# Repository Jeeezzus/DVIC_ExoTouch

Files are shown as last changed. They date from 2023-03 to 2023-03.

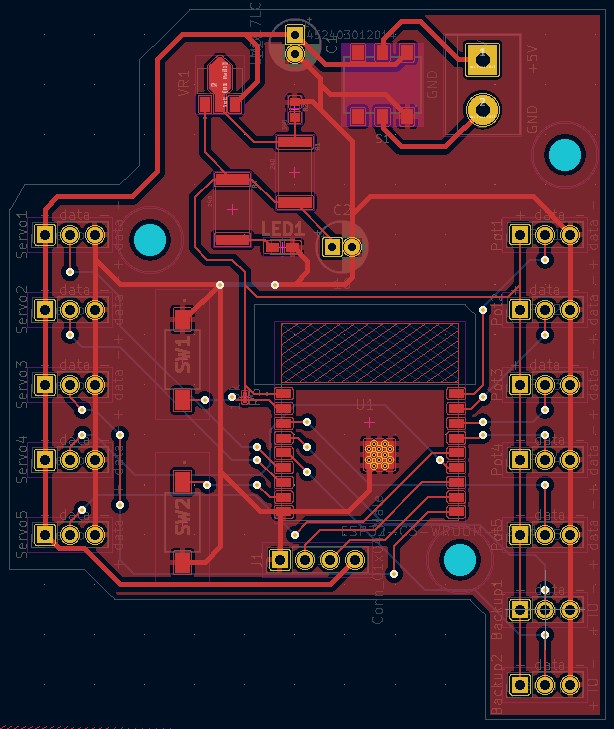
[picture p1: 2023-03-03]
HARDWARE/PCB/ScreenPCB.jpg

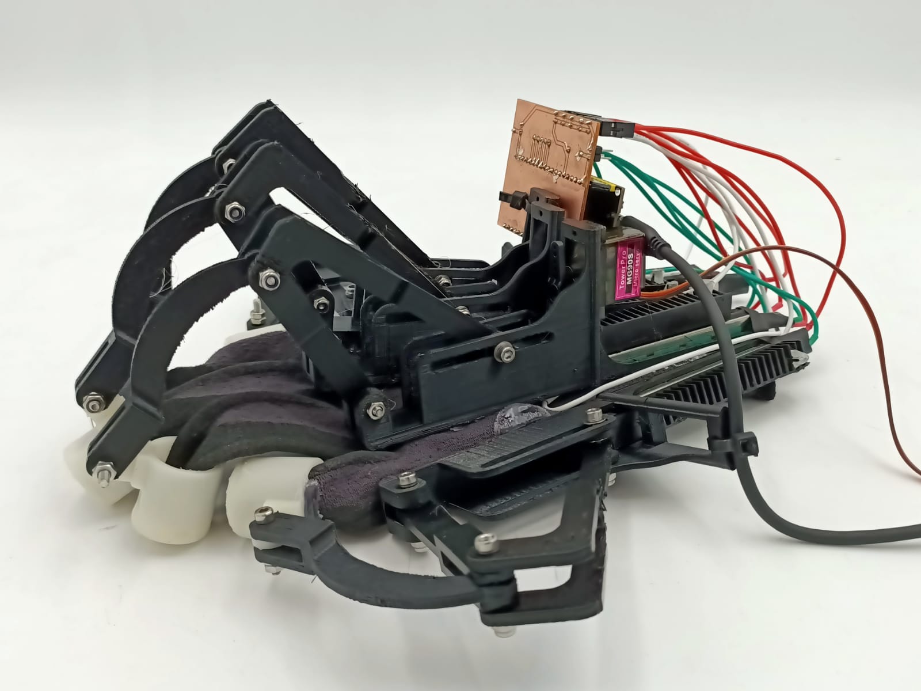
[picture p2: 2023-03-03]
Pictures/ExoTouchV2Packshot.jpeg

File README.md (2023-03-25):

# ExoTouch - DIY VR Haptic Glove

ExoTouch is an open-source project aimed at developing a DIY VR haptic glove that provides a realistic sense of touch for virtual reality experiences. This repository contains the hardware and software designs for several prototypes of the ExoTouch glove.

## Overview

We have produced several versions of the ExoTouch glove, each with different architectures and features, based on the  Lucid Glove: a cheap VR haptic glove that only requires potentiometers, servo motors, strings, and an ESP. It was designed By Lucas VRTech (all credits to https://github.com/LucidVR/lucidgloves)

The ExoTouch V1 is based on a three-piece exoskeleton that pulls a toothed bar that a servo-motor can lock to provide haptic feedback. The system was enhanced with a rudimentary PCB to control the servo motors and send the potentiometer information to the computer.

ExoTouch V2 was a prototype using a semi-rigid tube to connect the front of the finger to the potentiometer. However, this design was not promising and was quickly abandoned.

Finally, ExoTouch V3 is the latest version of the glove, based on the work of Nick Iacobbo. This exoskeleton follows each phalange of the hand, allowing much more efficient tracking of the position of the fingers. The potentiometers have been mounted on the back of the hand, offering better wrist flexibility. A rudimentary PCB has been added to send the potentiometer values to the computer, using an ESP32-based MCU board. This board includes a charge controller, allowing a battery to be directly connected to the ESP, making the glove wireless.

## Force Feedback System

The ExoTouch V3 introduced a new force feedback system, similar to bike brakes. Two brake plates are pressed against the potentiometer's moving part, introducing a friction force that blocks the fingers. Although the force feedback system is not as powerful as some commercial haptic gloves, it provides a realistic sense of touch for VR experiences.

## Limitations and Future Work

The ExoTouch gloves still have some limitations, including the force feedback system not being as strong as commercial gloves, the need to place the controller at the back of the hand, and the volume of the glove being a bit too large. However, we believe that this project can be improved by developing more powerful force feedback systems, improving the glove design, exploring alternative control mechanisms, and conducting further user studies to better understand the needs of different user groups.

## Conclusion

ExoTouch is a DIY VR haptic glove project that aims to provide a more immersive virtual reality experience. By sharing our designs and code, we hope to encourage others to experiment and improve upon our work. We welcome feedback, contributions, and collaborations from the community.

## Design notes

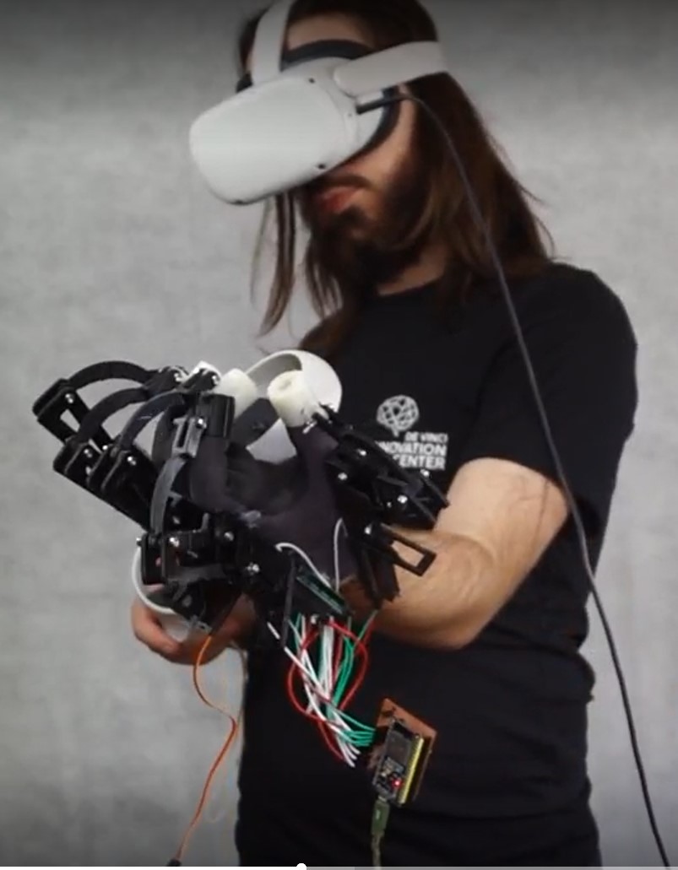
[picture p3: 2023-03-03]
Pictures/Using2.jpg

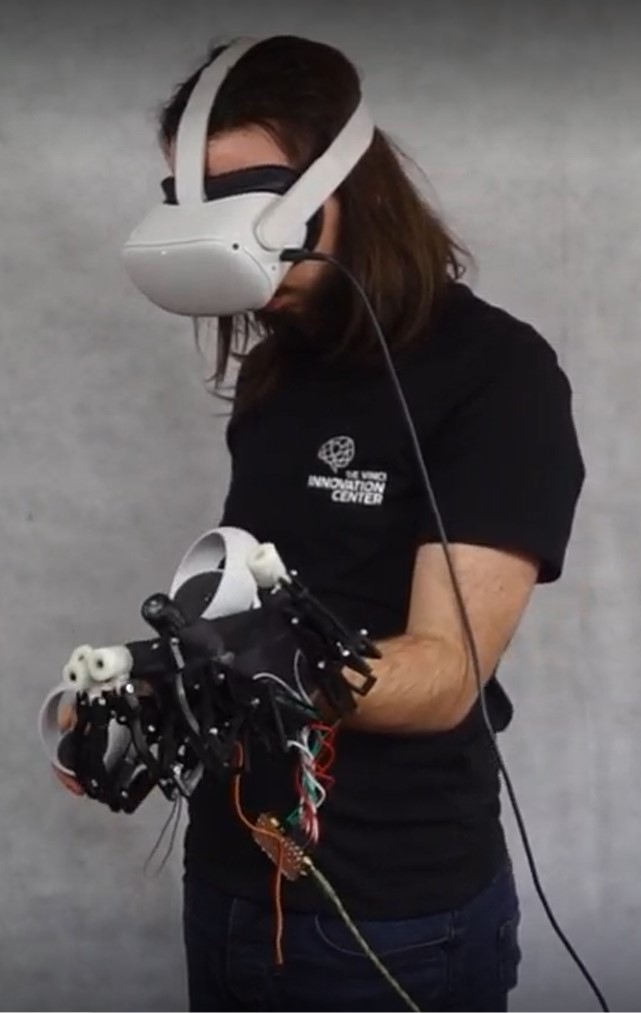
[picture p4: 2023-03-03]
Pictures/Using.jpg

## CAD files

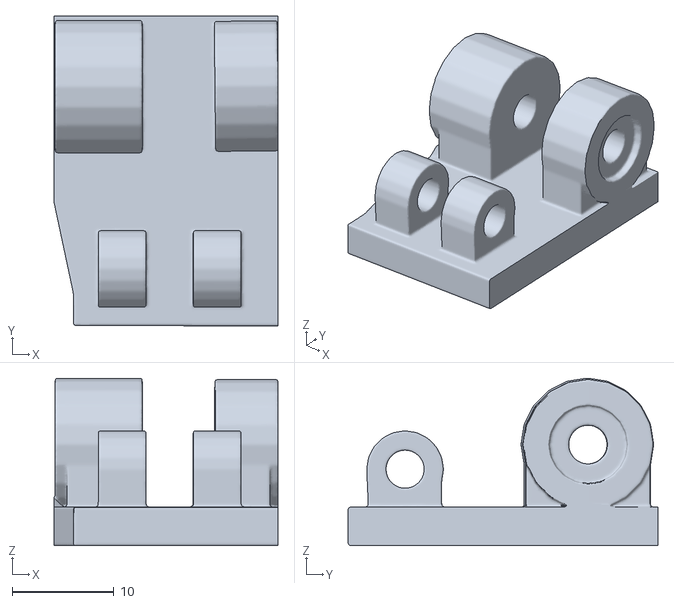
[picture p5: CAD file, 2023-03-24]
HARDWARE/V3/STL Files/GloveHolder.stl
22.0 x 30.5 x 16.5

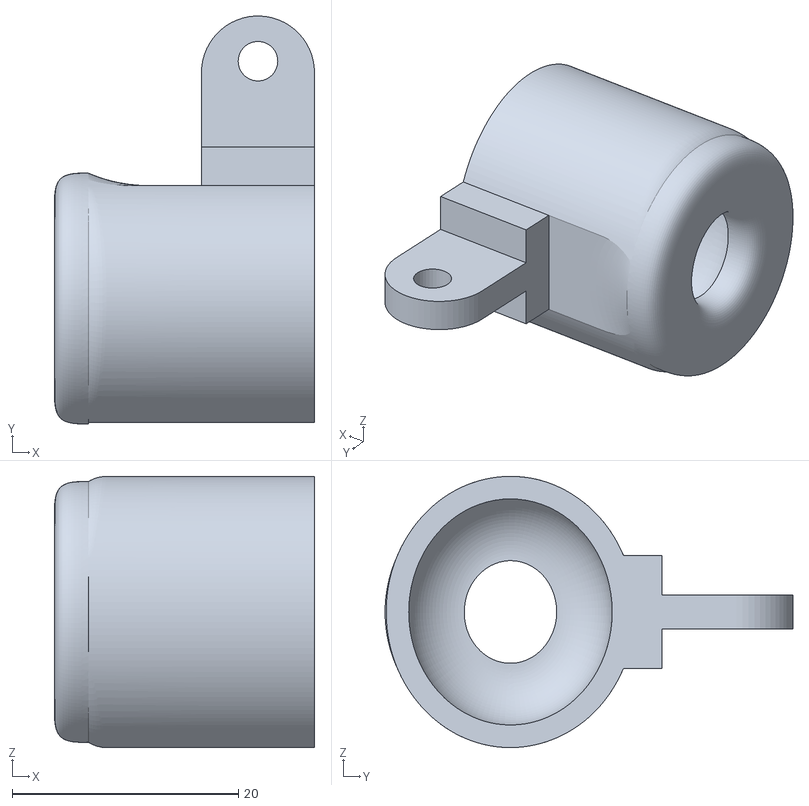
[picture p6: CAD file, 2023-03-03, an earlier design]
HARDWARE/V1/Cover doigt.stl
23.0 x 36.1 x 24.0

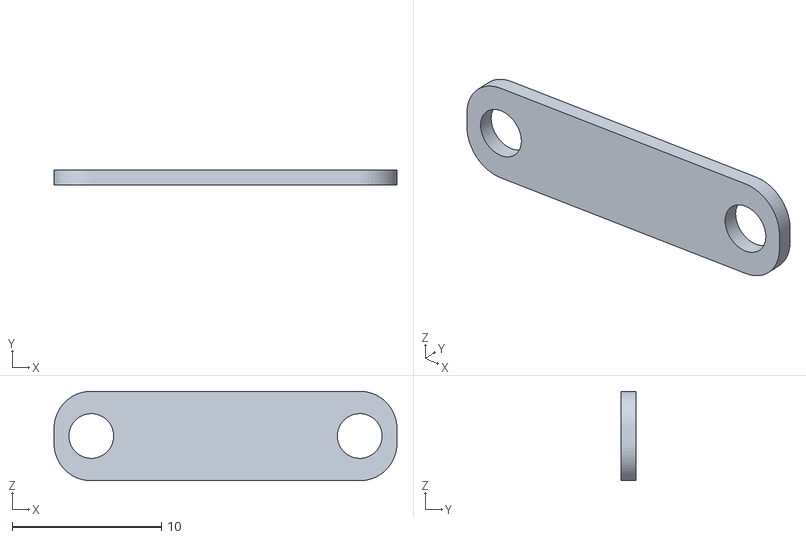
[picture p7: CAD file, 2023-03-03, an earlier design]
HARDWARE/V2/A23.stl
23.0 x 1.00 x 6.00

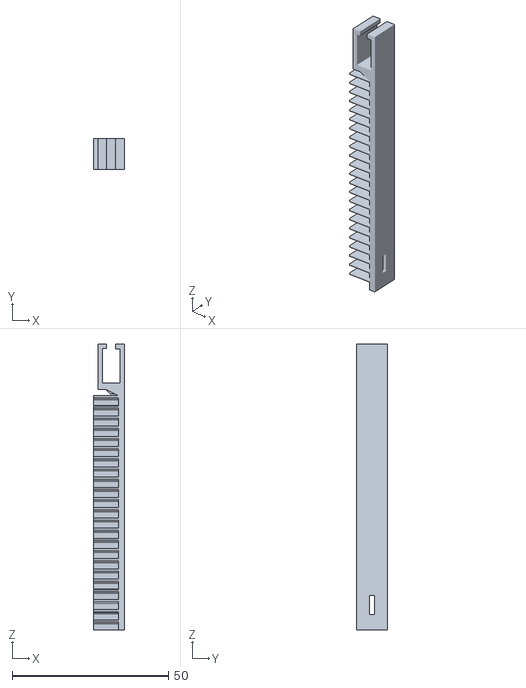
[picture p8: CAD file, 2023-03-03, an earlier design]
HARDWARE/V1/CoverPotard.stl
10.0 x 10.0 x 91.5

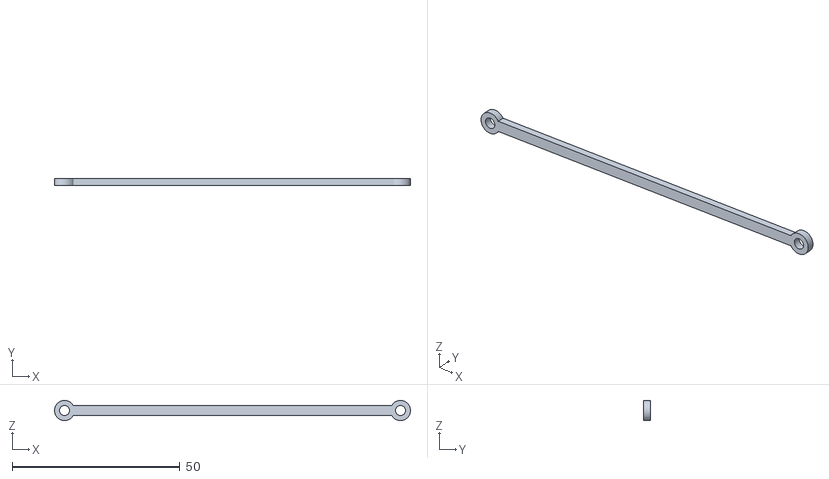
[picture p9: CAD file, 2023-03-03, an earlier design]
HARDWARE/V2/PSlider v2.stl
106.0 x 2.00 x 6.00

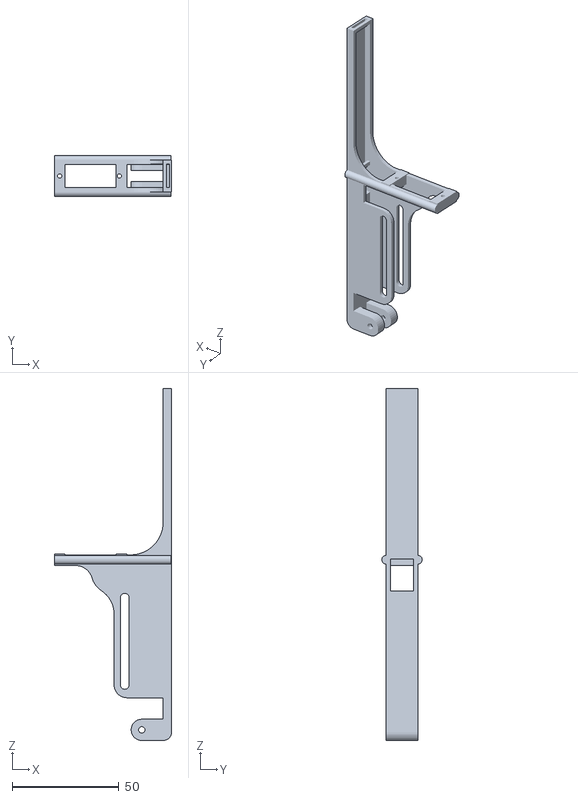
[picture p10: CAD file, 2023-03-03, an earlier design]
HARDWARE/V1/SupportPotard.stl
55.0 x 19.0 x 165.0

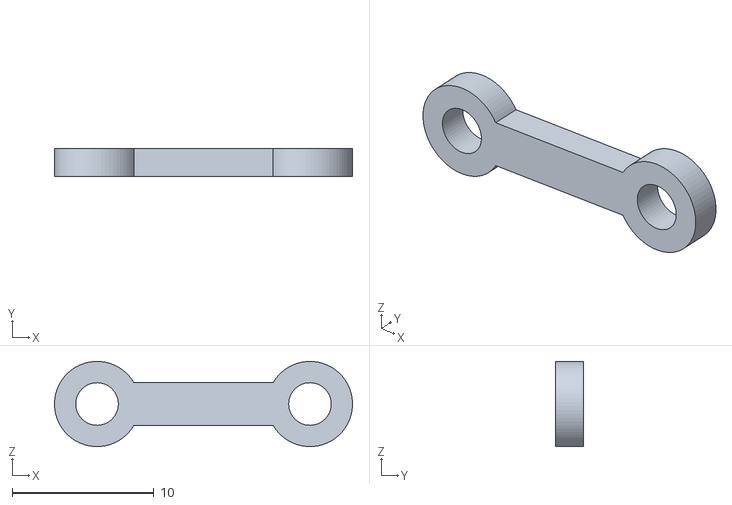
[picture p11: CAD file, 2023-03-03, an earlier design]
HARDWARE/V2/PUP.stl
21.0 x 2.00 x 6.00

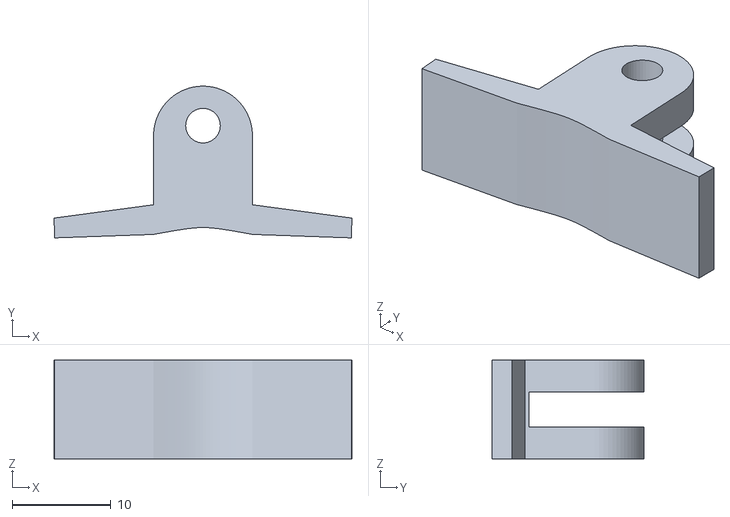
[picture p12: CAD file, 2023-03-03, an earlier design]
HARDWARE/V1/acrocheP1.stl
30.1 x 15.3 x 10.0

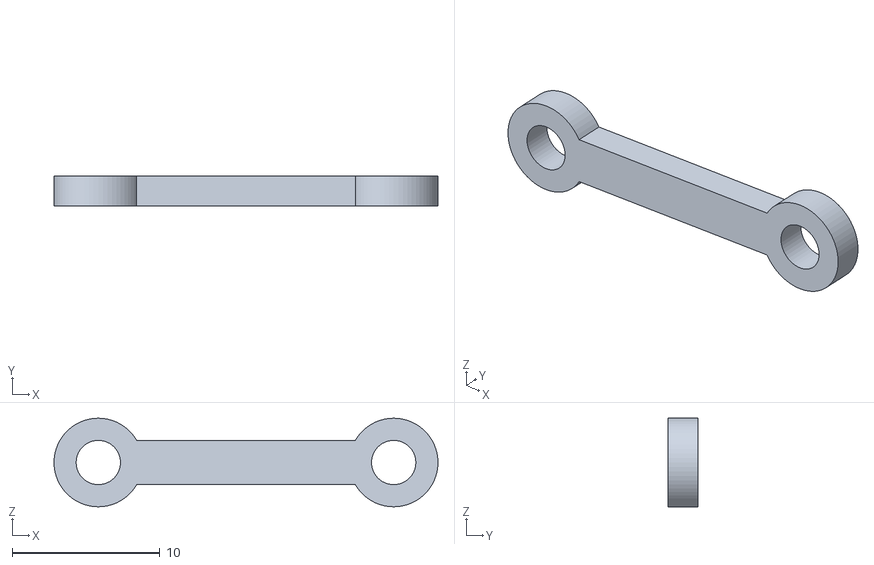
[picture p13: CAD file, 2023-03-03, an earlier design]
HARDWARE/V2/PUPBACK.stl
26.0 x 2.00 x 6.00

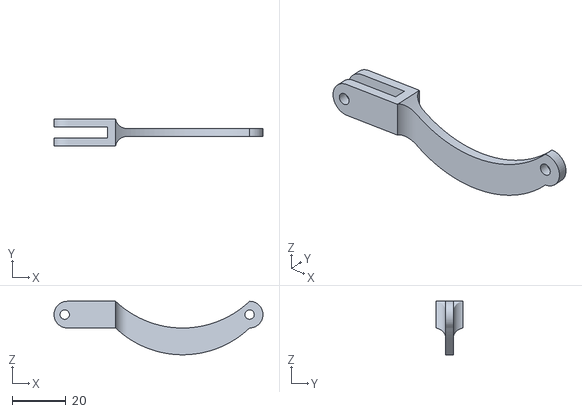
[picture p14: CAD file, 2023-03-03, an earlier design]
HARDWARE/V1/Courbe.stl
78.0 x 10.0 x 20.0

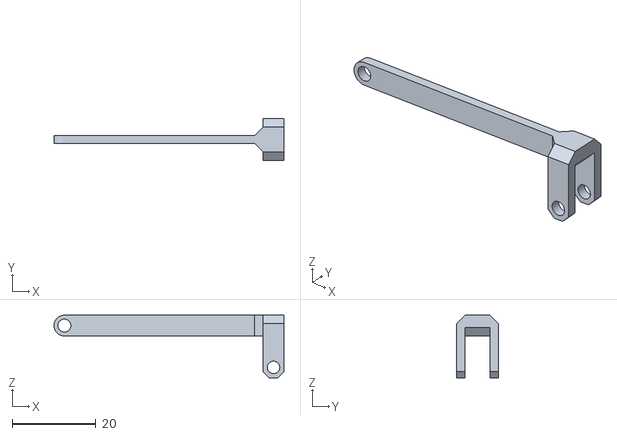
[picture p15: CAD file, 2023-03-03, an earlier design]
HARDWARE/V2/BarreP1.stl
55.0 x 10.0 x 15.0

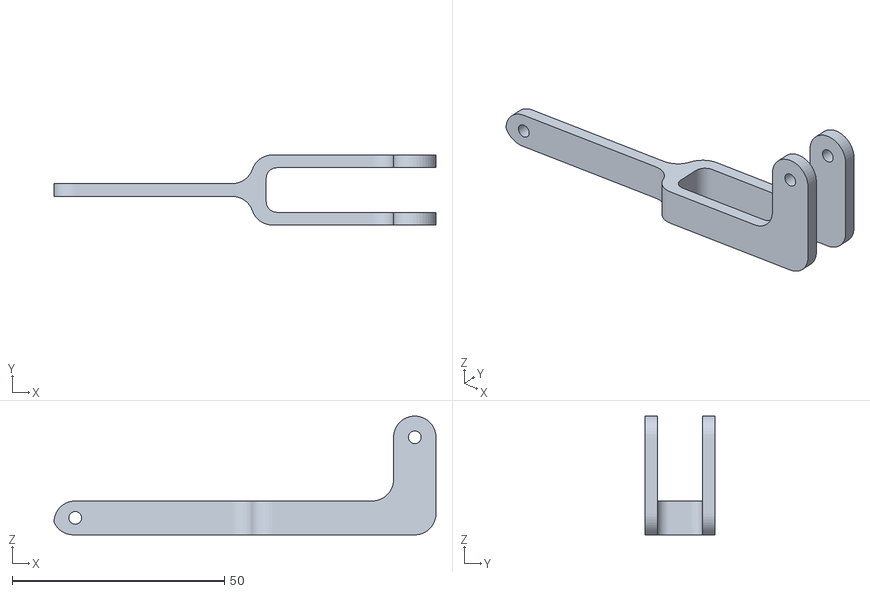
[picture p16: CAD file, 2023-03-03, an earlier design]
HARDWARE/V1/Barre 3.stl
90.0 x 16.5 x 28.0

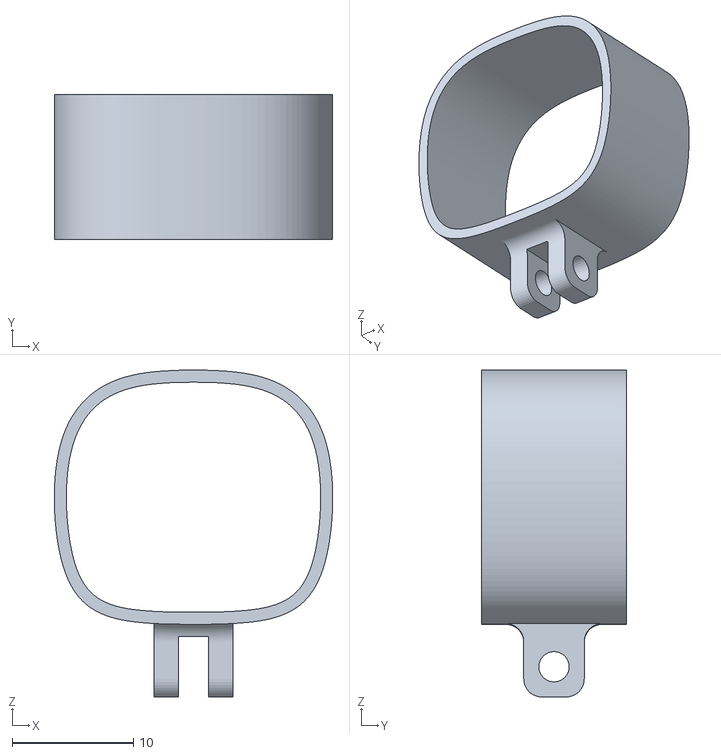
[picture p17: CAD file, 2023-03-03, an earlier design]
HARDWARE/V2/P2.stl
23.0 x 12.0 x 27.0

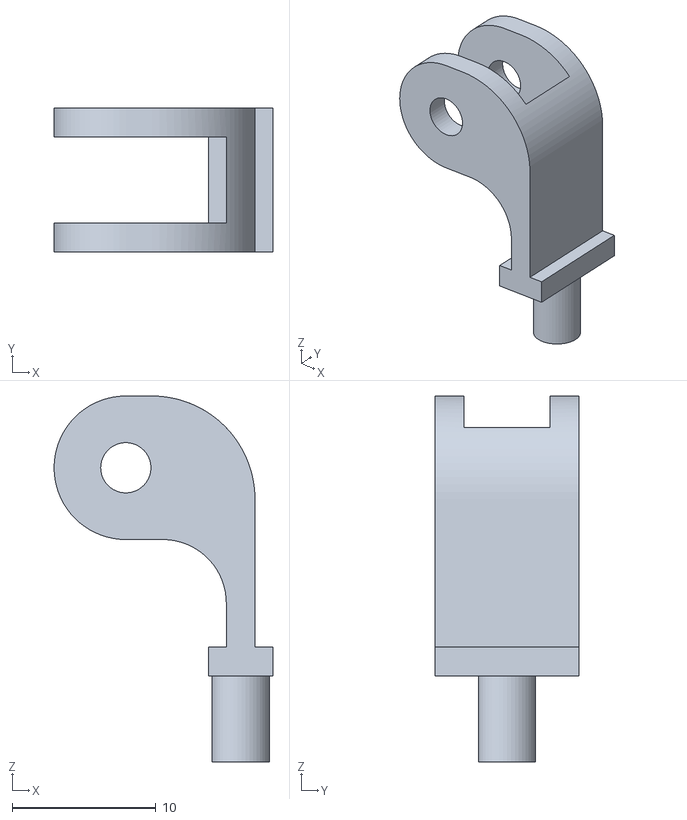
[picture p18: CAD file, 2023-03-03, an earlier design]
HARDWARE/V1/Pusher.stl
15.2 x 10.0 x 25.5

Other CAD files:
HARDWARE/V2/PBack.stl
HARDWARE/V1/B2.stl
HARDWARE/V2/A12.stl
HARDWARE/V2/P3.stl

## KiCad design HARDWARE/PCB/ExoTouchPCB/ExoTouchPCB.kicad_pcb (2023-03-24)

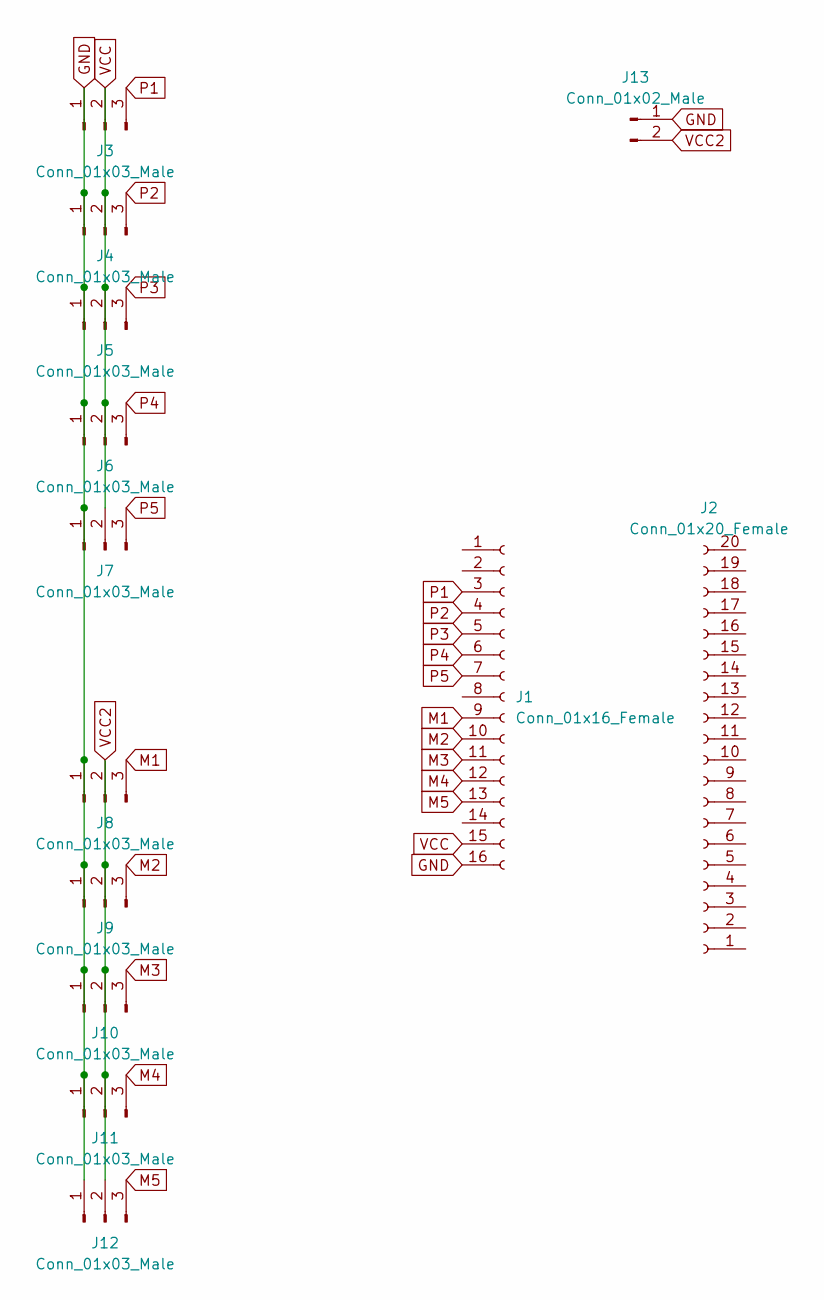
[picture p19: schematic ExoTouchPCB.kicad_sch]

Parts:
J1: Conn_01x16_Female; PinHeader_1x16_P2.54mm_Vertical
J2: Conn_01x20_Female; PinHeader_1x20_P2.54mm_Vertical
J3, J4, J5, J6, J7, J8, J9, J10, J11, J12: Conn_01x03_Male; PinHeader_1x03_P2.54mm_Vertical
J13: Conn_01x02_Male; PinHeader_1x02_P2.54mm_Vertical

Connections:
GND: J1.16, J3.1, J4.1, J5.1, J6.1, J7.1, J8.1, J9.1, J10.1, J11.1, J12.1, J13.1
M1: J1.9, J8.3
M2: J1.10, J9.3
M3: J1.11, J10.3
M4: J1.12, J11.3
M5: J1.13, J12.3
P1: J1.3, J3.3
P2: J1.4, J4.3
P3: J1.5, J5.3
P4: J1.6, J6.3
P5: J1.7, J7.3
VCC: J1.15, J3.2, J4.2, J5.2, J6.2, J7.2
VCC2: J8.2, J9.2, J10.2, J11.2, J12.2, J13.2

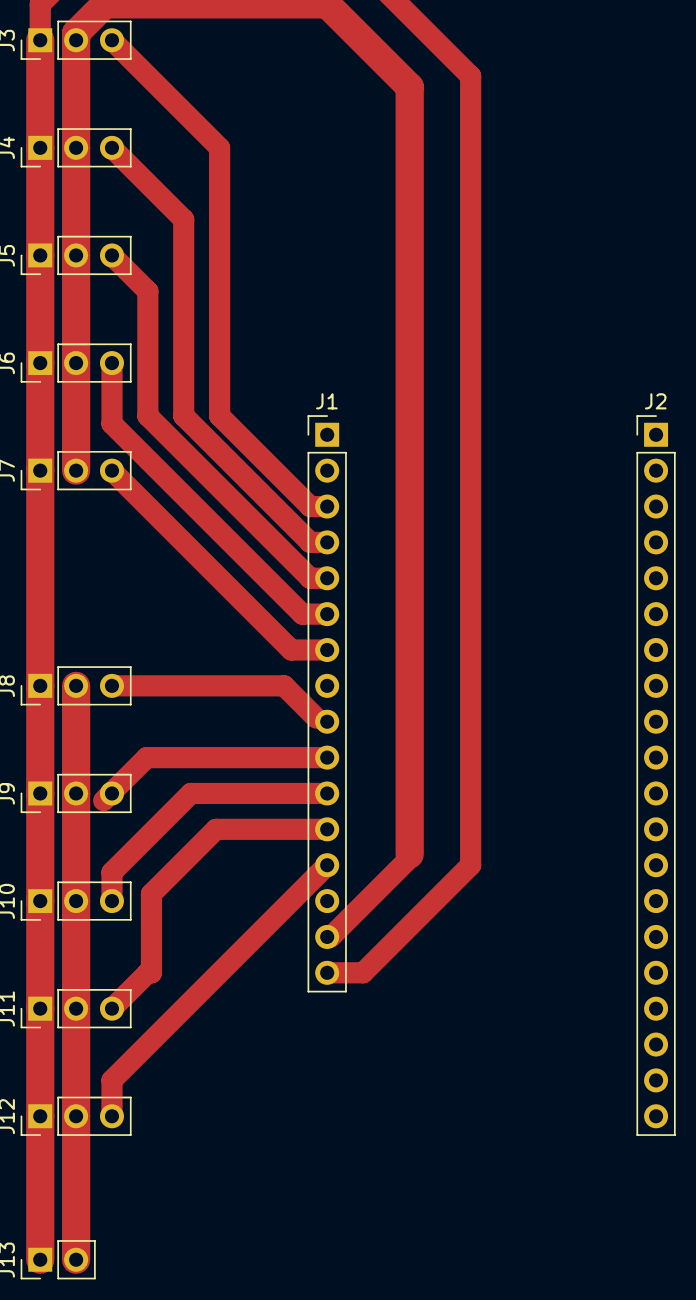
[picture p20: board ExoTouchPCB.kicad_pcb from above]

Board: 2 copper layers, 13 parts (0 on the bottom side), 13 nets.

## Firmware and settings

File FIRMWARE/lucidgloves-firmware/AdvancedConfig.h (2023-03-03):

//Advanced settings, only for the pros XD

#define LOOP_TIME 1 //How much time between data sends (ms), set to 0 for a good time :)
#define CALIBRATION_LOOPS -1//How many loops should be calibrated. Set to -1 to always be calibrated.

//Comm defines, no touchy
#define COMM_SERIAL 0   
#define COMM_BTSERIAL 1 

//Encoding
#define ENCODING 1
#define ENCODE_LEGACY 0
#define ENCODE_ALPHA  1

//Finger indeces (not used for legacy)
#define PINKY_IND 4
#define RING_IND 3
#define MIDDLE_IND 2
#define INDEX_IND 1
#define THUMB_IND 0

//Automatically set ANALOG_MAX depending on the microcontroller
#if defined(__AVR__)
#define ANALOG_MAX 1023
#elif defined(ESP32)
#define ANALOG_MAX 4095 
#endif


//ANALOG_MAX OVERRIDE:
//uncomment and set as needed (only touch if you know what you are doing)
//#define ANALOG_MAX 4095 

#ifndef ANALOG_MAX
#error "This board doesn't have an auto ANALOG_MAX assignment, please set it manually by uncommenting ANALOG_MAX OVERRIDE!"
#endif

//Filtering and clamping analog inputs
#define CLAMP_ANALOG_MAP true //clamp the mapped analog values from 0 to ANALOG_MAX

// Enable and set min and max to match your sensor's expected raw value range
// This discards any spurious values outside of the useful range
#define CLAMP_FLEXION false  //clamp the raw flexion values
#define CLAMP_MIN 0  //the minimum value from the flexion sensors
#define CLAMP_MAX ANALOG_MAX  //the maximum value from the flexion sensors

// You must install RunningMedian library to use this feature
// https://www.arduino.cc/reference/en/libraries/runningmedian/
#define ENABLE_MEDIAN_FILTER false //use the median of the previous values, helps reduce noise
#define MEDIAN_SAMPLES 20

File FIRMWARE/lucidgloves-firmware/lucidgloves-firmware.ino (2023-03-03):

/*
 * LucidGloves Firmware Version 4
 * Author: Lucas_VRTech - LucidVR
 * lucidvrtech.com
 */

 //modified by Gauthier

#include "AdvancedConfig.h"

//This is the configuration file, main structure in _main.ino
//CONFIGURATION SETTINGS:
#define COMMUNICATION COMM_SERIAL //Which communication protocol to use
//serial over USB
  #define SERIAL_BAUD_RATE 115200
  
//serial over Bluetooth
  #define BTSERIAL_DEVICE_NAME "lucidgloves-Left"

//ANALOG INPUT CONFIG
#define FLIP_POTS  true  //Flip values from potentiometers (for fingers!) if they are backwards

//Gesture enables, make false to use button override
#define TRIGGER_GESTURE true
#define GRAB_GESTURE    true
#define PINCH_GESTURE   true


//BUTTON INVERT
//If a button registers as pressed when not and vice versa (eg. using normally-closed switches),
//you can invert their behaviour here by setting their line to true.
//If unsure, set to false
#define INVERT_A false
#define INVERT_B false
#define INVERT_JOY false
#define INVERT_MENU false
#define INVERT_CALIB false
//These only apply with gesture button override:
#define INVERT_TRIGGER false
#define INVERT_GRAB false
#define INVERT_PINCH false


//joystick configuration
#define JOYSTICK_BLANK true //make true if not using the joystick
#define JOY_FLIP_X false
#define JOY_FLIP_Y false
#define JOYSTICK_DEADZONE 10 //deadzone in the joystick to prevent drift (in percent)

#define NO_THUMB false //If for some reason you don't want to track the thumb

#define USING_CALIB_PIN false //When PIN_CALIB is shorted (or it's button pushed) it will reset calibration if this is on.

#define USING_FORCE_FEEDBACK false //Force feedback haptics allow you to feel the solid objects you hold
#define SERVO_SCALING true //dynamic scaling of servo motors

#if defined(ESP32)
  //(This configuration is for ESP32 DOIT V1 so make sure to change if you're on another board)
  #define PIN_PINKY     25 
  #define PIN_RING      33
  #define PIN_MIDDLE    32
  #define PIN_INDEX     35
  #define PIN_THUMB     34
  #define PIN_JOY_X     43
  #define PIN_JOY_Y     45
  #define PIN_JOY_BTN   46
  #define PIN_A_BTN     47 
  #define PIN_B_BTN     14
  #define PIN_TRIG_BTN  12 //unused if gesture set
  #define PIN_GRAB_BTN  13 //unused if gesture set
  #define PIN_PNCH_BTN  23 //unused if gesture set
  #define PIN_CALIB     100 //button for recalibration (You can set this to GPIO0 to use the BOOT button, but only when using Bluetooth.)
  #define DEBUG_LED 2
  #define PIN_PINKY_MOTOR     16  //used for force feedback
  #define PIN_RING_MOTOR      17 //^
  #define PIN_MIDDLE_MOTOR    5 //^
  #define PIN_INDEX_MOTOR     18 //^
  #define PIN_THUMB_MOTOR     19 //^
  #define PIN_MENU_BTN        27

#endif
